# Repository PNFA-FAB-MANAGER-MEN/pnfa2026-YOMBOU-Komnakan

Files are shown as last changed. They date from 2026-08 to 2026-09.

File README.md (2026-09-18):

# Robot Éducatif à évitement d'obstacle télécommandé — Équipe 20

> Un robot à 2 roues qui détecte et évite les obstacles automatiquement, affiche la distance en temps réel sur un écran, et reste pilotable à tout moment par télécommande infrarouge.

**Vidéo de démonstration** : [Video de démonstration ](https://drive.google.com/example-lien-video-fabrication-pcb)

## Intention pédagogique

Technologie / algorithmique — [niveau à préciser], [effectif à préciser] — apprendre à écrire une logique de décision conditionnelle à partir d'une mesure physique réelle (distance), et comprendre le rôle d'un driver moteur dans la séparation des alimentations de puissance et de logique.

Lien : [séquence pédagogique](docs/03-sequence-pedagogique/plan-de-seance.md)

## Architecture

Capteur à ultrasons HC-SR04 → ESP32 DevKit → driver moteur TB6612FNG → moteurs DC. En parallèle : récepteur infrarouge (télécommande) → ESP32 DevKit → pilotage manuel ou bascule de mode. Retour visuel : ESP32 DevKit → écran OLED (distance mesurée, état du système).

## Sommaire du dépôt

| Dossier | Contenu |
|---|---|
| `docs/` | Fiche projet, cahier des charges, journal quotidien, séquence pédagogique, sécurité, alimentation, tests, guide de reproduction |
| `hardware/` | Schéma et routage PCB (KiCad), fichiers de fabrication de la carte |
| `firmware/` | Micrologiciel ESP32 (lecture ultrason, réception infrarouge, pilotage moteur, affichage OLED) |
| `bom/` | Nomenclature complète chiffrée |

## Avancement

| Jalon | Date | État | Release |
|---|---|---|---|
| J0 Lancement | 25/08 | ✅ | — |
| J1 Idée cadrée | 29/08 | ✅ | v0.1 |
| J2 Conception | 05/09 | ✅ | v0.2 |
| J3 Prototype | 12/09 | ✅ | v0.5 |
| J4 Intégration | 16/09 | ✅ | v0.9 |
| Gel du dépôt | 17/09 18 h | ⬜ | v1.0 |

## Reproduire ce dispositif

Renvoi : [guide de reproduction](docs/06-guide-de-reproduction.md) — coût estimé : [à chiffrer] FCFA.

## Licences

- **Logiciel** : MIT — pour permettre la réutilisation libre du firmware par d'autres Fab Managers.
- **Matériel** : [CERN-OHL-S v2, -W ou -P à préciser] — motivation en une phrase.
- **Documentation et médias** : CC BY-SA 4.0 — pour que la documentation reste ouverte et partageable dans le réseau PNFA.

## Crédits et remerciements

Bibliothèques utilisées : réception infrarouge (IRremote ou équivalent), affichage OLED (Adafruit SSD1306 + GFX). INFPP Lomé pour l'accueil du FabLab. [Personnes ressources à ajouter]

---

*Projet intégrateur PNFA 2026-2027 · Certification 1 — Praticien · INFPP / MEN*

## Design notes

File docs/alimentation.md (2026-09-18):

# Bilan de puissance et alimentation

> Exigence ET-ELEC-04 · Livrable L7 · Jalon J3. **Marge ≥ 30 %.**

| Élément | Tension | Courant nominal | Courant de pic | Remarque |
|---|---|---|---|---|
| ESP32 DevKit | 3,3 V (logique, régulée en interne depuis 5 V) | 80 mA | 500 mA | Le pic survient lors des transmissions Wi-Fi/Bluetooth |
| Récepteur infrarouge (télécommande) | 3,3–5 V | 5 mA | 5 mA | |
| Capteur à ultrasons HC-SR04 | 5 V | 15 mA | 15 mA | Sortie ECHO en 5 V logique : nécessite un diviseur de tension avant d'entrer sur une broche ESP32 (3,3 V) |
| Écran OLED I2C (SSD1306) | 3,3–5 V | 20 mA | 30 mA | |
| Driver moteur TB6612FNG — partie logique (VCC) | 3,3–5 V | 5 mA | 10 mA | |
| Driver moteur TB6612FNG — partie puissance (VM) | 7,4 V | — | — | Alimente directement les moteurs, voir ligne suivante |
| Moteur DC (× 2) | 7,4 V (via VM du driver) | 150–250 mA chacun | 800–1000 mA chacun (blocage/démarrage) | Le TB6612FNG supporte 1,2 A continu et 3,2 A crête par canal, largement suffisant |
| **Total rail logique (3,3–5 V)** | | **≈ 110 mA** | **≈ 550 mA** | ESP32 + capteur ultrason + écran OLED + récepteur IR |
| **Total rail moteur (7,4 V)** | | **≈ 300–500 mA** | **jusqu'à ≈ 2 A (les deux moteurs bloqués en même temps)** | Cas rare, mais à couvrir par la marge |

**Source retenue** : ☒ batterie + charge — **2 accumulateurs Li-ion en série, 7,4 V nominal**, dédiés exclusivement à l'alimentation moteur via le driver TB6612FNG.
**Capacité de la source** : [à préciser — capacité en mAh indiquée sur vos accumulateurs]
**Marge calculée** : le TB6612FNG (1,2 A continu / 3,2 A crête par canal) offre une marge largement supérieure à 30 % par rapport au courant de pic estimé (≈ 2 A cumulé sur les deux canaux, soit 1 A par canal en pire cas) — marge disponible ≈ 20 % sur le pic extrême, mais confortable (> 100 %) en fonctionnement normal (≈ 250 mA/canal).

## Masse commune et protections

**Contexte** : le 12 septembre 2026, un retour de tension par le port USB a endommagé la carte mère de l'ordinateur utilisé pour la programmation (voir `docs/04-securite/analyse-risques.md`). Le schéma d'alimentation ci-dessous a été revu pour que cela ne se reproduise plus.

- **Deux rails d'alimentation strictement séparés** : le rail logique (ESP32, capteurs, écran, LED) reste alimenté soit par le câble USB de programmation, soit par une source 5 V régulée — jamais par les accumulateurs moteur directement. Le rail moteur (7,4 V) alimente uniquement l'entrée VM du TB6612FNG.
- **Masse commune obligatoire** : la masse (GND) du rail logique et celle du rail moteur doivent être reliées entre elles au niveau du driver TB6612FNG (c'est ce point commun qui permet à l'ESP32 de piloter le driver), **mais jamais leurs alimentations positives**.
- **Ordre de branchement** : brancher et vérifier la masse commune avant de mettre sous tension le rail moteur ; ne jamais brancher l'ordinateur (USB) en même temps qu'un tout premier essai d'un nouveau câblage de puissance non encore vérifié.
- **Vérification avant chaque mise sous tension** : contrôle visuel du câblage + multimètre, comme désormais indiqué dans `docs/04-securite/analyse-risques.md`.

## Conformité ES-02

Très basse tension seule accessible (≤ 12 V continu — ici 7,4 V maximum). Accumulateurs lithium protégés, inaccessibles aux élèves en dehors de leur logement, chargés selon la règle du réseau et uniquement sous surveillance d'un adulte.

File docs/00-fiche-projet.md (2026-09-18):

# Fiche projet — Équipe 20

> Livrable L2 · Jalon J1 (samedi 29 août 2026) · validée par l'encadreur référent.
> Aucune fabrication n'est autorisée avant la validation de ce jalon.
> **Version mise à jour le 16 septembre 2026** pour refléter le dispositif final, après plusieurs itérations matérielles documentées dans le journal (voir notamment l'entrée du 12 septembre).

## 1. Titre et accroche

**Robot Éducatif — évitement d'obstacle télécommandé, avec affichage de distance en temps réel**

Un robot à 2 roues qui détecte les obstacles par ultrason, les évite automatiquement par une manœuvre de rotation signalée par une LED, affiche la distance mesurée en temps réel sur un écran, et reste pilotable à tout moment par télécommande.

## 2. Besoin et bénéficiaires

L'initiation à la robotique et à la programmation embarquée manque souvent de support concret et réutilisable dans les établissements. Un robot éducatif compact, combinant mesure physique (distance), décision automatique (évitement) et retour visuel immédiat (écran, LED), offre un support réutilisable pour enseigner la logique de décision conditionnelle à partir de données de capteur réelles.

- **Élèves concernés** : élèves du club sciences/technologie ou d'une classe de technologie, niveau collège ou lycée
- **Discipline d'usage** : technologie et algorithmique
- **Établissement / lab d'accueil** : INFPP Lomé

## 3. Objectifs d'apprentissage

1. **Algorithmique.** Écrire une boucle de décision conditionnelle qui compare une mesure de distance à un seuil et déclenche une manœuvre d'évitement.
2. **Physique appliquée.** Expliquer le principe de mesure d'un capteur à ultrasons (émission, écho, temps de vol) à partir de la valeur affichée en temps réel sur l'écran du robot.
3. **Électronique de puissance.** Décrire le rôle d'un driver moteur (pont en H) et la nécessité de séparer l'alimentation de puissance des moteurs de l'alimentation logique — enseignement tiré directement de l'incident du 12 septembre 2026 (voir `docs/04-securite/analyse-risques.md`).

## 4. Description du dispositif
**Ce que l'objet fait** : le robot avance et mesure en continu la distance à l'obstacle le plus proche grâce à un capteur à ultrasons. Tant que la voie est libre, la LED rouge reste éteinte. Dès que le robot détecte un obstacle, la LED rouge s'allume. Un récepteur de télécommande permet à tout moment de commander le robot (marche, arrêt, avance) indépendamment de la logique automatique d'évitement.

**Ce que l'élève en fait** : il observe la correspondance entre la valeur affichée à l'écran et le comportement réel du robot, règle le seuil de déclenchement de l'évitement, et peut reprendre la main par télécommande pour comparer pilotage manuel et comportement autonome.

**Croquis** : Le schéma du dispositif est téléversé dans docs/medias/.

## 5. Architecture technique et liste des composants

| Composant | Rôle | Quantité |
|---|---|---|
| Carte ESP32 DevKit | Contrôleur principal | 1 |
| Châssis robot 2 roues + moteurs DC | Structure mobile et motorisation | 1 kit |
| Driver moteur TB6612FNG | Pilotage des 2 moteurs DC | 1 |
| Capteur à ultrasons HC-SR04 | Détection d'obstacle / mesure de distance | 1 |
| Écran OLED I2C | Affichage de la distance en temps réel | 1 |
| Récepteur infrarouge + télécommande | Pilotage manuel du robot | 1 |
| Bouton poussoir | Activation / changement de mode | 1 |
| LED rouge | Voyant « obstacle détecté » (fixe), puis clignotant pendant la rotation d'évitement | 1 |
| Résistance (220 Ω pour la LED) | Limitation de courant | 1
/ |
| Accumulateurs Li-ion 7,4 V (2 éléments en série) | Alimentation dédiée du rail moteur | 1 pack |
| Câbles jumpers, breadboard | Câblage de prototypage | selon besoin |

## 6. Rôle des élèves

Les élèves conçoivent, câblent et programment eux-mêmes la logique de décision (seuil de distance, manœuvre d'évitement) et le partage entre pilotage automatique et pilotage par télécommande.

## 7. Ancrage réseau et implantation

- **Lieu d'usage** : salle de classe ou club robotique, sol plat dégagé pour les tests de déplacement
- **Conditions matérielles** : zone de test dégagée d'au moins quelques mètres, accumulateurs chargés à l'avance

## 8. Périmètre

| | Contenu |
|---|---|
| Dans la v1.0 (Socle) | Mesure de distance en continu, affichage temps réel sur écran, évitement automatique avec signalisation LED, pilotage par télécommande |
| En option (Avancé / Expert) | Réglage du seuil d'évitement par télécommande plutôt que dans le code |
| Explicitement exclu | Microphone, capteur de lumière (LDR), buzzer — retirés du périmètre final après les itérations matérielles de début septembre |

## 9. Risques et parades

Voir `docs/04-securite/analyse-risques.md` pour le tableau complet, incluant l'incident réel du 12 septembre 2026 (retour de tension USB ayant endommagé la carte mère de l'ordinateur de programmation) et les mesures de séparation des rails d'alimentation désormais appliquées.

## 10. Budget matière estimé

*À chiffrer par l'équipe — plafond indicatif : 60 000 FCFA.*

| Poste | Estimation (FCFA) |
|---|---|
| ESP32 DevKit, châssis + moteurs, driver TB6612FNG | [à chiffrer] |
| Capteur ultrason, écran OLED, récepteur IR + télécommande | [à chiffrer] |
| LED, résistances, bouton, câblage | [à chiffrer] |
| Accumulateurs Li-ion 7,4 V | [à chiffrer] |
| **Total estimé** | [à chiffrer] |

## 11. Licences et diffusion

Code proposé sous licence libre (MIT, cohérente avec le fichier `LICENSE` du dépôt). Documentation et plans proposés sous licence Creative Commons BY-SA (cohérente avec `LICENSE-DOCS` et `LICENSE-HARDWARE`).

## Exemptions demandées

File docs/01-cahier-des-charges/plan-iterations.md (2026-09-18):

# Plan d'itérations

> Livrable L3 · Jalon J2. Découpage du projet en lots et en tâches d'une demi-journée
> au plus, chacune avec un titulaire unique et une issue GitHub associée.
> **Mis à jour le 16 septembre 2026** pour refléter l'état réel d'avancement (voir le journal, notamment les entrées du 9 au 16 septembre).

| Lot | Tâche | Titulaire | Issue | Jalon | État |
|---|---|---|---|---|---|
| Cadrage | Rédiger et faire valider la fiche projet | Komnakan YOMBOU | #1 | J1 | fait |
| Cahier des charges | Rédiger le besoin et les fonctions de service | Komnakan YOMBOU | #2 | J2 | fait |
| Cahier des charges | Tracer l'idéation (pistes explorées, critères, motifs) | Komnakan YOMBOU | #3 | J2 | fait |
| Cahier des charges | Découper le plan d'itérations | Komnakan YOMBOU | #4 | J2 | fait |
| Carte électronique | Mini-projet KiCad d'entraînement (symboles, empreintes, carte XIAO) | Komnakan YOMBOU | #5 | J2 | fait (9 sept.) |
| Carte électronique | Câbler le circuit sous Fritzing | Komnakan YOMBOU | #6 | J2 | fait, puis abandonné faute de simulation (10 sept.) |
| Carte électronique | Tester les composants reçus (LCD, LED, XIAO) | Komnakan YOMBOU | #7 | J2 | fait (10-11 sept.) |
| Carte électronique | Arbitrer le choix définitif de carte et de driver moteur | Komnakan YOMBOU | #8 | J2-J3 | fait — ESP32 DevKit + TB6612FNG (itérations du 11 au 15 sept.) |
| Carte électronique | Concevoir le schéma définitif et router le PCB sous KiCad | Komnakan YOMBOU | #9 | J3-J4 | fait (16 sept.) |
| Carte électronique | Fabriquer le PCB (gravure/perçage) | Komnakan YOMBOU | #10 | J4 | fait (16 sept.) |
| Mécanique | Assembler le châssis, les moteurs à engrenages | Komnakan YOMBOU | #11 | J2-J3 | fait |
| Firmware | Programmer la lecture ultrason et la logique d'évitement | Komnakan YOMBOU | #12 | J2-J4 | fait (16 sept.) |
| Firmware | Programmer la réception de la télécommande infrarouge et la bascule manuel/automatique | Komnakan YOMBOU | #13 | J3-J4 | fait (15-16 sept.) |
| Firmware | Intégrer l'affichage sur écran OLED (distance, état du système) | Komnakan YOMBOU | #14 | J3 | fait |
| Sécurité | Rédiger l'analyse de risques, incluant l'incident du 12 septembre | Komnakan YOMBOU | #15 | J3 | fait |
| Alimentation | Rédiger le bilan de puissance et séparer les rails moteur/logique | Komnakan YOMBOU | #16 | J3 | fait |
| Tests | Écrire le cahier de tests (au moins 10 cas, dont 2 de sécurité) | [Komnakan YOMBOU] | #17 | J4 | à faire |
| Tests | Faire reproduire le dispositif par une autre équipe à partir du dépôt seul | [Komnakan YOMBOU] | #18 | J4 | à faire — dépend de la disponibilité d'une équipe testeuse |
| Documentation | Rédiger le guide de reproduction complet | [Komnakan YOMBOU] | #19 | avant le gel | à faire |
| Documentation | Compléter la séquence pédagogique, tester la séance sur une autre équipe | [Komnakan YOMBOU] | #20 | avant le gel | à faire — compte rendu du test à verser dès qu'il a lieu |
| Soutenance | Préparer le plan de démonstration minuté | [Komnakan YOMBOU] | #21 | avant le gel | à faire |

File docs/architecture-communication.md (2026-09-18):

# Architecture de communication

> Exigences ET-COM-01 à ET-COM-03 · Jalon J4.

## Identifiant du dispositif

Dérivé de l'adresse MAC de l'ESP32 DevKit, même si le lien de commande retenu n'est pas un lien réseau — inscrit au plan d'adressage de la promotion.

## Schéma bloc

Télécommande infrarouge → récepteur IR (ESP32) → logique de décision embarquée → driver moteur TB6612FNG → moteurs. En parallèle : capteur ultrason → ESP32 → écran OLED (affichage distance et état).

## Liaison retenue et justification

☒ **Autre : liaison infrarouge unidirectionnelle** (télécommande → récepteur IR embarqué)
☐ MQTT vers tableau de bord local (Node-RED) avec commande retour
☐ ESP-NOW / radio avec nœud secondaire et accusé de réception

**Justification** : le dispositif ne nécessite pas de tableau de bord distant ni de nœud secondaire — c'est un robot autonome et localement télécommandé. La liaison infrarouge est volontairement simple, sans réseau, ce qui satisfait par construction l'exigence de fonctionnement hors internet (EF-03). **Point à valider avec l'encadreur** : cette architecture ne correspond à aucune des deux options cochables du gabarit (MQTT / ESP-NOW) ; à confirmer si une exemption ou une note d'adaptation est nécessaire pour ET-COM-01/02.

## Robustesse (ET-COM-03)

| Situation | Comportement défini |
|---|---|
| Perte de liaison (télécommande hors de portée ou hors ligne de vue) | Le robot ignore les signaux non reçus ; en mode manuel sans nouvelle commande, il s'arrête après un court délai plutôt que de continuer indéfiniment sur la dernière commande reçue *(délai exact à fixer par l'équipe)* |
| Reconnexion | Reprise immédiate dès réception d'un nouveau signal IR valide, aucune procédure d'appairage nécessaire |
| Valeurs par défaut | Au démarrage, le robot est en mode automatique (évitement d'obstacle) tant qu'aucune commande manuelle n'est reçue |
| Période d'émission | Sur événement uniquement (appui sur la télécommande), pas d'émission périodique |

**La démonstration se fait sans internet** — déjà garanti par construction, la liaison IR ne dépendant d'aucune infrastructure réseau.

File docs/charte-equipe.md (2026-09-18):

# Charte de l'équipe 20

> Livrable L1 · Jalon J0 (mardi 25 août 2026) · exigée à la revue J1.
> Complétée le 16 septembre 2026 — en retard sur le jalon J0, à régulariser au plus vite.

## Identité

**Dépôt** `pnfa2026-YOMBOU-Komnakan`
**Groupe pédagogique** [à préciser] · **Encadreur référent** [à préciser]

## Règles de décision

1. **Réunion quotidienne** debout à l'accueil, 10 min, animée par le chef de projet :
   fait hier / prévu aujourd'hui / blocages, puis mise à jour du tableau de projet.
2. **Décision** — recherche du consensus ; à défaut, le chef de projet tranche et la
   décision est consignée dans la rubrique « Décidé » du journal, avec son motif.
3. **Définition de « terminé »** — le livrable existe, il a été vérifié par un autre
   membre, l'entrée de journal est poussée et l'issue est fermée par le commit qui la résout.
4. **Documentation** — chacun rédige sa part avant de quitter le pôle. Le responsable
   documentation vérifie, il ne rédige pas à la place.
5. **Poussée** — vers GitHub au moins deux fois par jour, midi et soir.
   Rien ne reste sur un seul poste.
6. **Sécurité électrique** — règle ajoutée suite à l'incident du 12 septembre 2026 : aucun nouveau câblage de puissance (moteurs, driver) n'est mis sous tension avec l'ordinateur de programmation encore branché tant que le câblage n'a pas été vérifié par un second membre de l'équipe.

## Engagements de présence

- Absence : prévenir le chef de projet ; les tâches en cours sont réassignées le jour même.
- Désaccord persistant : porté à l'encadreur référent sous 24 h.
- Chaque membre s'engage à pouvoir expliquer l'ensemble du dispositif à la soutenance.]

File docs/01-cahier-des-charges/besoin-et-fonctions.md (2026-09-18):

# Cahier des charges fonctionnel

> Livrable L3 · Jalon J2. **Mis à jour le 16 septembre 2026** pour refléter le dispositif final (évitement d'obstacle + télécommande infrarouge, sans LED ni suivi de ligne).

## Énoncé du besoin

Le robot rend service aux élèves d'un club de robotique ou d'une classe de technologie qui souhaitent s'initier concrètement à la programmation embarquée et à la mesure physique. Il agit sur son propre déplacement (évitement d'obstacle automatique, pilotage manuel par télécommande) et sur l'affichage en temps réel de la distance mesurée et de l'état du système. Le but est de fournir un support pédagogique réutilisable pour enseigner la logique de décision algorithmique à partir de données de capteur réelles, plutôt qu'à partir d'un exercice sur feuille.

## Fonctions de service et contraintes

| Réf. | Fonction | Critère | Niveau visé | Flexibilité |
|---|---|---|---|---|
| FS1 | Détecter et éviter un obstacle frontal | Distance de détection avant réaction | Seuil réglable, de l'ordre de 15 à 20 cm | Élevée — réglable en code |
| FS2 | Afficher en continu la distance mesurée et l'état du système sur écran | Délai de rafraîchissement de l'affichage | ≤ 1 seconde | Élevée |
| FS3 | Être piloté manuellement par télécommande infrarouge (avancer, tourner à gauche, tourner à droite) | Délai de réponse à une commande | ≤ 0,5 seconde | Faible — nécessaire à la démonstration |
| FS4 | Basculer entre mode manuel et mode automatique par télécommande | Fiabilité de la bascule | 100 % des essais | Faible |
| FC1 | Fonctionner sur une alimentation autonome (accumulateurs) | Autonomie minimale pendant une séance | ≥ 30 minutes d'utilisation continue | Faible |
| FC2 | Séparer l'alimentation de puissance des moteurs de l'alimentation logique | Aucun retour de tension vers l'ordinateur de programmation | 0 incident (exigence tirée de l'incident du 12 septembre 2026) | Aucune — non négociable |
| FC3 | Être pris en main par un élève sans formation préalable | Temps de prise en main | ≤ 10 minutes (exigence EF-04) | Faible |
| FC4 | Rester transportable et de mise en service rapide | Dimensions et temps de mise en service | ≤ 60 × 60 × 60 cm, mise en service ≤ 5 min (exigence EF-05) | Faible |

## Déclinaison des exigences fonctionnelles du programme

| Réf. CDC | Exigence | Déclinaison sur ce projet | Vérification prévue |
|---|---|---|---|
| EF-01 | Intention pédagogique explicite | Initier les élèves à la logique de décision algorithmique et à la mesure physique via un robot à évitement d'obstacle télécommandé | Séquence pédagogique testée sur une autre équipe (`docs/03-sequence-pedagogique/`) |
| EF-02 | Mesure et action sur le monde physique | Chaîne mesure → décision → action : capteur ultrason → logique embarquée → moteurs (évitement) et écran (affichage) ; réception IR → logique embarquée → moteurs (pilotage manuel) | Cahier de tests (`docs/05-tests/`) démontrant chaque chaîne mesure-décision-action |
| EF-03 | Restitution exploitable hors internet | Affichage embarqué sur écran OLED, fonctionnement entièrement autonome, sans connexion réseau nécessaire | Test de fonctionnement complet, connexion internet coupée |
| EF-04 | Prise en main élève ≤ 10 min | Télécommande à boutons simples (avancer, gauche, droite, bascule de mode), comportement du robot immédiatement observable | Test utilisateur chronométré |
| EF-05 | Transportable, ≤ 60 × 60 × 60 cm, mise en service ≤ 5 min | Châssis compact sur accumulateurs, sans branchement secteur nécessaire | Mesure physique du châssis + chronométrage de la mise en service |

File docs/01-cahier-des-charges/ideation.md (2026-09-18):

# Idéation

> Livrable L3 · Jalon J2. Trace des pistes explorées avant le choix du sujet :
> divergence, critères de tri, sujet retenu et motifs du rejet des autres.

## Critères de tri utilisés

Trois critères ont guidé la comparaison de toutes les pistes, du début à la fin de la recherche :

1. **Faisabilité technique** — niveau de prérequis, risques signalés, temps de fabrication tenable dans le calendrier, dépendance aux machines partagées du FabLab
2. **Pertinence éducative** — lien réel avec un besoin d'établissement ou un contenu de programme, bénéficiaire identifiable
3. **Richesse en compétences acquises** — diversité des procédés de fabrication mobilisés (exigence ET-FAB-02) et des notions techniques nouvelles

## Pistes explorées, dans l'ordre chronologique

| Piste | Origine | Ce qui a été retenu | Motif du rejet ou de l'abandon |
|---|---|---|---|
| P047 — Tableau d'appel visuel | Recueil des 150 projets | Meilleure pertinence éducative (accessibilité, Voie 1) et bonne faisabilité (Niveau 1) | Non rejetée sur le fond, mais l'équipe a préféré une piste combinant davantage de procédés de fabrication |
| P061 — Bras robotisé de tri | Recueil des 150 projets | Meilleure richesse de compétences (4 procédés : laser, impression, moulage, carte) | Projet démonstrateur de FabLab, sans apport concret installé pour un usager extérieur |
| P066 — Fontaine à eau filtrée supervisée | Recueil des 150 projets | Apport concret durable + richesse technique équivalente à P061 | Niveau 2, charge de maintenance (calibrage du capteur de turbidité) jugée lourde pour le calendrier |
| P124 — Détecteur de porte restée ouverte | Recueil des 150 projets | Très bonne faisabilité (Niveau 1, aucun risque réel) | Bénéficiaire limité à un usage interne de sécurité, pertinence éducative jugée faible |
| P139 — Alarme de niveau de bac | Recueil des 150 projets | Bonne faisabilité, notion intéressante de redondance de capteurs | Bénéficiaire = le FabLab lui-même, portée jugée trop restreinte |
| **P126 — Indicateur de niveau sonore de classe** | Recueil des 150 projets | **Choisi le 29 août** : Niveau 1, Voie 1 (dispositif didactique), pertinence forte (autorégulation du bruit de classe), enrichi d'un bouton Mode Cours propre à l'équipe | Abandonné ensuite au profit d'un projet jugé plus riche techniquement par l'équipe |
| Combinaison P137 (horloge parlante) + P146 (tableau de score sportif) | Piste personnalisée | Idée de mutualiser le matériel (audio, afficheur) entre deux notices | Rejetée : deux usages sans rapport, discours de soutenance dilué entre deux messages différents |
| Combinaison P137 (horloge parlante) + afficheur d'informations d'établissement (heure / cours / pause / communiqué) | Piste personnalisée | Combinaison plus cohérente que la précédente (même finalité : informer sur le temps et la vie scolaire), double accessibilité (visuelle et vocale) | Complexité de gestion d'un emploi du temps programmé jugée trop lourde pour le calendrier restant |
| Armoire de rangement sécurisée (badge RFID + code à 4 chiffres + alarme anti-effraction) | Piste personnalisée, hors recueil | Projet très riche (authentification double facteur, verrouillage motorisé, détection d'intrusion), entièrement simulable numériquement (aucun capteur analogique à calibrer) | Écartée en raison du courant élevé demandé par la serrure solénoïde 12 V (risque électrique de conception) et du temps de fabrication d'une structure d'armoire jugé trop long pour le calendrier |
| **Robot Éducatif multi-capteurs** | Piste personnalisée, hors recueil | **Sujet retenu** | — |

## Motifs du choix final

Le Robot Éducatif a été retenu parce qu'il réunit ce que les pistes précédentes offraient séparément :

- **Faisabilité maîtrisée** : un châssis 2 roues + roue folle (motricité et rotation adaptées au suivi de ligne, contrairement à un châssis 4 roues moins précis en virage), une architecture électronique simulable presque entièrement avant fabrication
- **Richesse de compétences** : mécanique (moteurs, driver, châssis), plusieurs familles de capteurs (infrarouge, ultrason, microphone, luminosité), affichage, algorithmique de décision
- **Continuité pédagogique** : le module capteur de son et de lumière réutilise directement les acquis des ateliers du 27 et 28 août (CyberPi, capteur de lumière, mesure sonore), et la logique de décision reprend les mêmes principes que le projet P126 initialement retenu (seuils, moyenne, réaction du dispositif)
- **Objet démontrable en direct** : contrairement à un dispositif installé et invisible dans son fonctionnement quotidien, un robot mobile offre une démonstration immédiate et intuitive devant le jury

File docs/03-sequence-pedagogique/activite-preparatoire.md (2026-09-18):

# Activité préparatoire débranchée ou par blocs

> Exigence EP-06 · reliée au fonctionnement du dispositif (issue d'UC8-M2 ou M3).

**Objectif** : faire vivre la logique « mesure → seuil → décision » sans robot ni code, avant de l'observer sur le vrai dispositif.

**Déroulé (15-20 min)** : les élèves se mettent par deux. L'un joue le rôle du capteur : les yeux bandés, il avance à petits pas et annonce à voix haute une distance estimée à chaque pas (« trois pas », « deux pas »...). L'autre joue le rôle du programme : il a reçu une règle simple écrite sur une carte (« si la distance annoncée est inférieure à deux pas, dis STOP puis TOURNE »). Dès que la règle se déclenche, le binôme mime la manœuvre d'évitement.

**Lien avec le dispositif** : cette règle papier est exactement celle qui sera ensuite écrite en code (comparaison d'une distance mesurée à un seuil, déclenchement d'une action). L'activité rend visible, avant tout code, ce que fait réellement le capteur à ultrasons du robot.

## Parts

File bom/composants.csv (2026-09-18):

sous_ensemble | reference | designation | boitier_ou_format | quantite | procede_ou_source | fournisseur | prix_unitaire_fcfa | prix_total_fcfa | etat
pcb | PCB1 | Carte electronique definitive | PCB grave/perce, concu sous KiCad | 1 | fabrique | INFPP Lome | 0 | 0 | fabrique
pcb | U1 | Microcontroleur ESP32 DevKit | module | 1 | achat | magasin PNFA | [a chiffrer] | [a chiffrer] | monte
pcb | U2 | Driver moteur TB6612FNG | module | 1 | achat | magasin PNFA | [a chiffrer] | [a chiffrer] | monte
pcb | - | Recepteur infrarouge (telecommande) | module | 1 | achat | magasin PNFA | [a chiffrer] | [a chiffrer] | monte
pcb | - | Telecommande infrarouge | boitier | 1 | achat | magasin PNFA | [a chiffrer] | [a chiffrer] | fourni avec le recepteur
pcb | - | Capteur a ultrasons HC-SR04 | module | 1 | achat | magasin PNFA | [a chiffrer] | [a chiffrer] | monte
pcb | - | Ecran OLED I2C | module | 1 | achat | magasin PNFA | [a chiffrer] | [a chiffrer] | monte
pcb | - | Fils de connexion / nappe | - | 1 lot | achat | magasin PNFA | [a chiffrer] | [a chiffrer] | monte
structure | - | Chassis robot 2 roues + moteurs DC a engrenages | kit | 1 | achat | magasin PNFA | [a chiffrer] | [a chiffrer] | monte
structure | - | Entretoises et visserie d'assemblage | M3 ou equivalent | 1 lot | achat | magasin PNFA | [a chiffrer] | [a chiffrer] | monte
alimentation | ALIM1 | Accumulateurs Li-ion 7,4 V (2 elements en serie) | pack | 1 | achat | magasin PNFA | [a chiffrer] | [a chiffrer] | monte
firmware | - | Bibliotheque de reception infrarouge (IRremote ou equivalent) | - | 1 | telechargement | bibliotheque libre | 0 | 0 | installe
firmware | - | Bibliotheque ecran OLED (Adafruit SSD1306 + GFX) | - | 1 | telechargement | bibliotheque libre | 0 | 0 | installe
TOTAL | - | Cout matiere total | - | - | - | - | - | [a chiffrer] | -

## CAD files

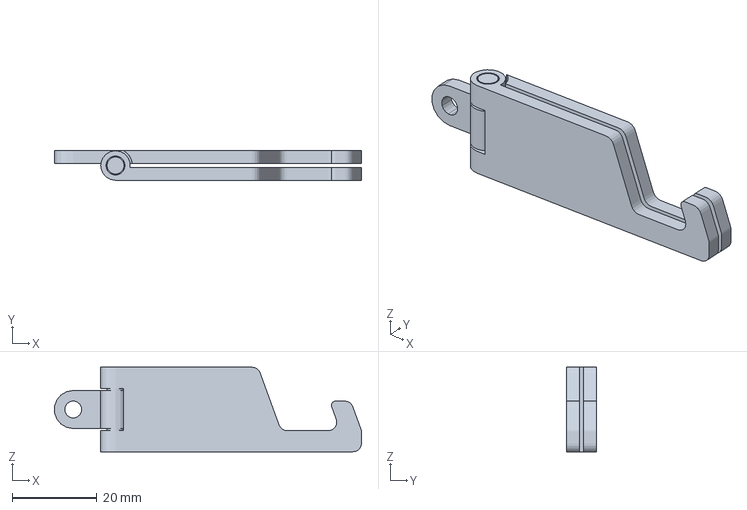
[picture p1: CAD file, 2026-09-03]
hardware/3dprint/Foldable_Phone_Stand_Bambu.3mf
72.6 x 7.00 x 20.0 mm

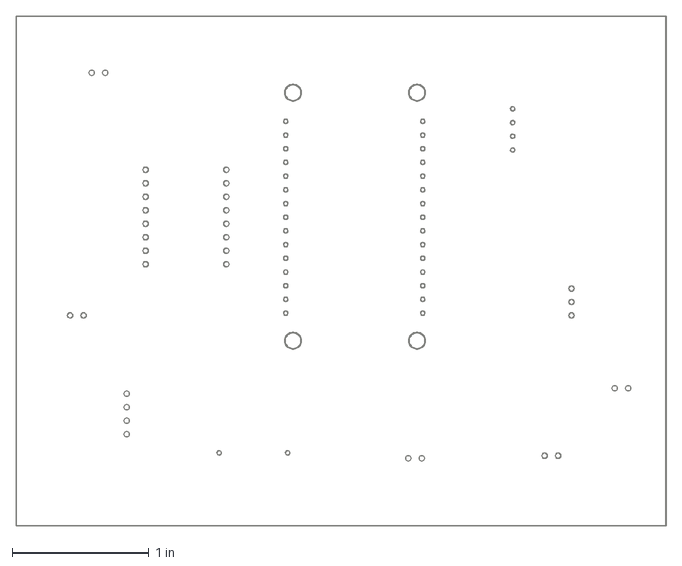
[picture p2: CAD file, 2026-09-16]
hardware/pcb/2026-09-16-ROBOT_EDU-Edge_Cuts.dxf
4.75 x 3.72 in

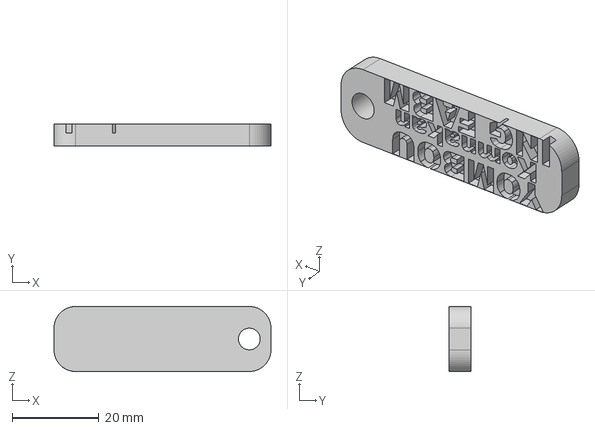
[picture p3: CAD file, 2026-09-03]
hardware/3dprint/YOMBOU-Porte-Clé.step
50.0 x 5.00 x 15.0 mm

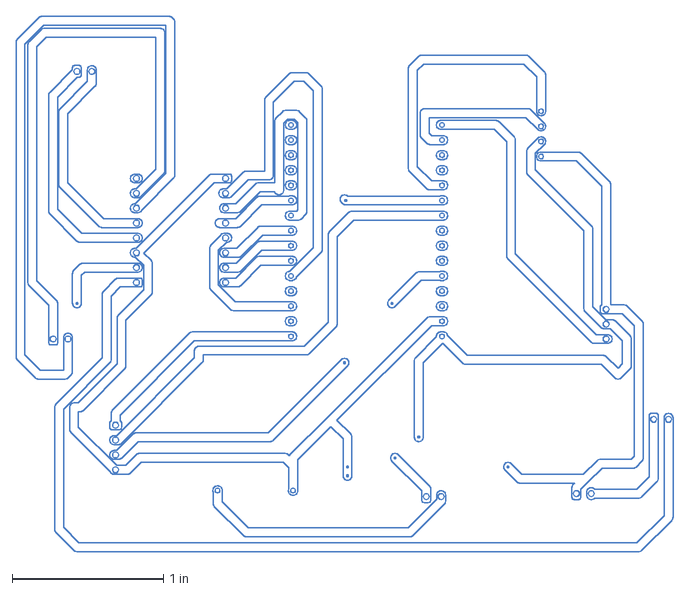
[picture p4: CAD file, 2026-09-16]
hardware/pcb/2026-09-16-ROBOT_EDU-B_Cu.dxf
4.35 x 3.54 in

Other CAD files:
hardware/3dprint/Foldable_Phone_Stand_Bambu.gcodeYK.gcode.3mf
hardware/3dprint/Foldable_Phone_Stand_Bambu.stl

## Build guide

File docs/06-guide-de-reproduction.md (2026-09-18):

# Guide de reproduction

> Exigence ED-13 · Livrable L10 · doit permettre à un Fab Manager tiers de reproduire
> le dispositif **sans contacter l'équipe**. C'est ce document que vérifie le test ED-14.

## 1. Ce que fait ce dispositif

Un robot à 2 roues, piloté par un ESP32 DevKit, qui détecte automatiquement les obstacles grâce à un capteur à ultrasons et les évite, affiche en continu la distance mesurée et l'état du système sur un écran OLED, et reste pilotable manuellement (avancer, tourner à gauche, tourner à droite, bascule manuel/automatique) par une télécommande infrarouge.

## 2. Outillage et machines requis

| Machine ou outil | Caractéristique minimale | Substitution possible |
|---|---|---|
| Poste de fraisage/gravure de PCB | Compatible avec les fichiers KiCad fournis | Toute machine de gravure/fraisage de circuit imprimé du FabLab |
| Ordinateur avec IDE de programmation | Arduino IDE (ou équivalent supportant l'ESP32) | Tout poste capable de téléverser du firmware sur ESP32 par USB |
| Multimètre | Mesure de tension continue | — |
| Fer à souder | Pour l'assemblage de la carte définitive | — |

## 3. Nomenclature chiffrée

## 4. Fichiers à utiliser, dans l'ordre

| Ordre | Étape | Fichier | Dossier |
|---|---|---|---|
| 1 | Comprendre le besoin et l'architecture | `00-fiche-projet.md` | `docs/` |
| 2 | Consulter la nomenclature | `composants.csv` | `bom/` |
| 3 | Ouvrir le schéma et le routage de la carte | [nom du projet KiCad à préciser] | `hardware/pcb/` |
| 4 | Fabriquer la carte | `fraisage.md` | `hardware/pcb/` |
| 5 | Assembler le châssis et les moteurs | [fichiers CAO du châssis, si produits, sinon notice du kit commercial] | `hardware/cad/` |
| 6 | Compiler et téléverser le firmware | code source ESP32 | `firmware/src/` |
| 7 | Mettre en service | Section 8 ci-dessous | — |

## 5. Paramètres machine

### Découpe laser

### Impression 3D

### Fraisage/gravure de la carte

## 6. Montage, étape par étape

Chaque étape est photographiée. Photos dans `docs/medias/`, ≤ 500 Ko.

1. Souder les composants sur la carte fraisée/gravée, en vérifiant chaque piste au multimètre avant mise sous tension
2. Fixer les moteurs et le driver TB6612FNG sur le châssis
3. Câbler le capteur ultrason, l'écran OLED et le récepteur infrarouge sur la carte
4. Brancher le rail moteur (accumulateurs 7,4 V) **séparément** du rail logique — voir `docs/alimentation.md`, section « masse commune et protections »
5. Vérifier la masse commune avant toute mise sous tension

## 7. Compilation et téléversement du micrologiciel

Renvoi : [`firmware/CONVENTIONS.md`](../firmware/CONVENTIONS.md)

## 8. Mise en service

1. Vérifier que les accumulateurs sont chargés
2. Mettre le robot sous tension : l'écran OLED doit afficher l'état « prêt »
3. Choisir le mode (manuel ou automatique) par la télécommande
4. Placer le robot dans une zone dégagée avant tout essai en mode automatique

## 9. Dépannage — les cinq pannes les plus probables

| Symptôme | Cause probable | Vérification | Correction |
|---|---|---|---|
| 1 | L'écran OLED reste noir | Mauvaise adresse I2C ou câblage SDA/SCL inversé | Vérifier le câblage et l'adresse I2C dans le code | Corriger le câblage ou l'adresse dans le firmware |
| 2 | Le robot ne réagit pas à la télécommande | Récepteur IR mal orienté ou pile de la télécommande faible | Tester avec une télécommande neuve, vérifier l'alignement | Réorienter le récepteur, changer la pile |
| 3 | Le robot ne détecte jamais les obstacles | Capteur ultrason mal câblé ou seuil mal réglé | Relire la distance affichée à l'écran face à un obstacle connu | Vérifier le câblage TRIG/ECHO, ajuster le seuil |
| 4 | Les moteurs ne tournent pas ou tournent faiblement | Accumulateurs déchargés ou rail moteur mal alimenté | Mesurer la tension aux bornes du driver | Recharger les accumulateurs, vérifier le câblage du rail moteur |
| 5 | L'ordinateur redémarre ou se coupe au branchement du montage | Retour de tension USB — voir l'incident du 12 septembre 2026 | Vérifier que les masses sont bien reliées et les rails séparés | Ne jamais tester un nouveau câblage de puissance avec l'ordinateur branché ; voir `docs/04-securite/analyse-risques.md` |

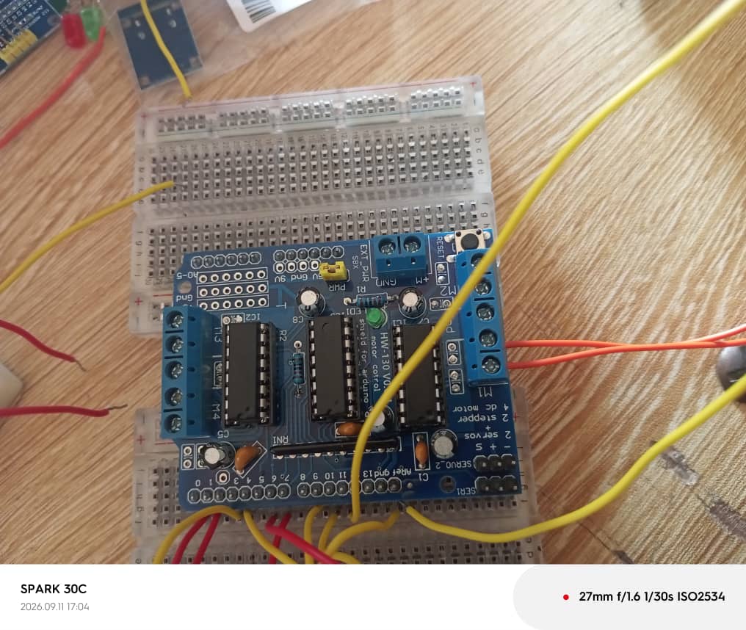
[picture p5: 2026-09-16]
docs/medias/2026-09-12-montage-00.jpeg

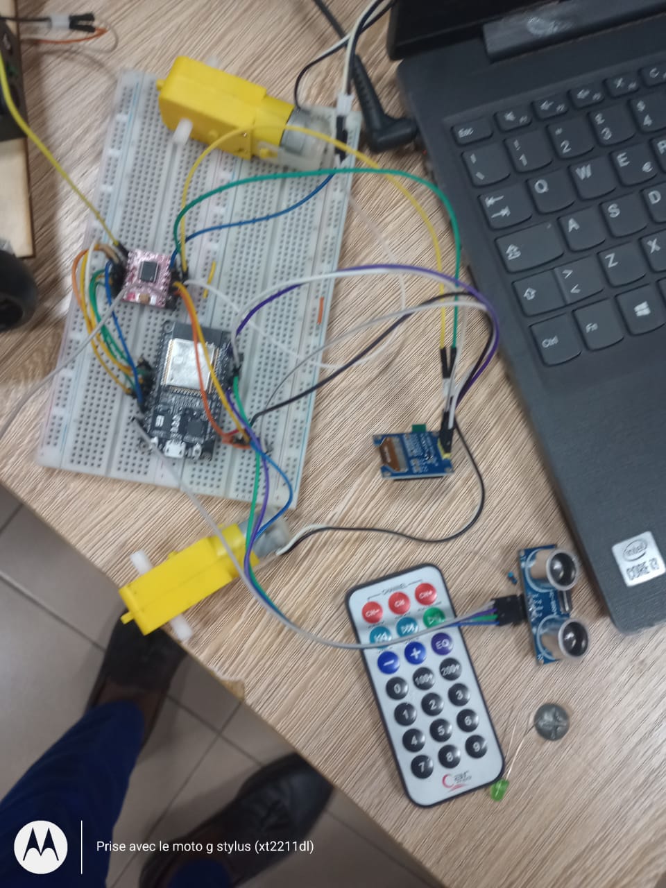
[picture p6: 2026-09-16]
docs/medias/2026-09-16-MONTAGE-PROTOTYPE.jpeg

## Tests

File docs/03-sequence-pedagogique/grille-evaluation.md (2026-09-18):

# Grille d'évaluation des apprentissages

> Exigence EP-05 · Livrable L5 · Jalon J2. Au moins quatre critères à quatre niveaux,
> indicateurs observables, incluant le processus (sécurité, coopération, documentation)
> et pas seulement le produit.

| Critère | Insuffisant | Fragile | Satisfaisant | Expert |
|---|---|---|---|---|
| Logique conditionnelle (seuil de distance) | Ne modifie pas le seuil ou provoque une erreur de code | Modifie le seuil avec aide, sans expliquer l'effet attendu | Modifie le seuil seul et prédit correctement le comportement du robot | Modifie le seuil et propose une justification chiffrée du choix retenu |
| Principe de mesure ultrason | Ne sait pas dire comment le robot « voit » la distance | Sait qu'un signal est émis et reçu, sans plus de détail | Explique émission/écho/temps de vol avec ses mots | Relie le principe à une limite concrète du capteur (angle, portée) observée sur le robot |
| Sécurité électrique (séparation des alimentations) | Ne sait pas pourquoi les deux rails sont séparés | Sait qu'il y a deux alimentations, sans expliquer pourquoi | Explique le risque de retour de tension et la nécessité de séparer les rails | Relie l'explication à l'incident réel du 12 septembre 2026 et propose une vérification avant mise sous tension |
| Processus : sécurité et coopération | Ne respecte pas les consignes de manipulation, travaille seul sans échange | Respecte les consignes avec rappel | Respecte les consignes seul et collabore avec le binôme | Respecte les consignes, aide un pair et documente sa manipulation |

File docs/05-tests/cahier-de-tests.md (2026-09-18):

# Cahier de tests

> Exigence ET-FW-04 · Livrable L9 · Jalon J4. Au moins dix cas : nominaux, limites
> et pannes, dont **deux cas de sécurité**. Chaque anomalie majeure correspond à une
> issue GitHub fermée avec sa cause.
>
> Les cas ci-dessous sont définis à partir du comportement attendu du dispositif.
> Les colonnes « Résultat obtenu » et « Verdict » sont à compléter par l'équipe lors de l'exécution réelle des tests.

| # | Type | Cas testé | Résultat attendu | Résultat obtenu | Verdict | Issue |
|---|---|---|---|---|---|---|
| 1 | nominal | Obstacle placé à 50 cm devant le robot en mode automatique | Le robot avance, la distance affichée diminue en continu sur l'OLED | | | |
| 2 | nominal | Obstacle atteignant le seuil réglé (ex. 15 cm) | Le robot déclenche la manœuvre d'évitement, l'écran indique l'état « obstacle » | | | |
| 3 | nominal | Commande « avancer » reçue par télécommande en mode manuel | Le robot avance tant que le bouton est actionné | | | |
| 4 | nominal | Bascule télécommande du mode manuel vers le mode automatique | Le robot reprend la logique d'évitement automatique dès la bascule | | | |
| 5 | limite | Obstacle placé exactement à la distance seuil (ni plus près, ni plus loin) | Comportement cohérent et reproductible (pas d'oscillation entre les deux états) | | | |
| 6 | limite | Obstacle très proche (moins de 2 cm, sous la portée minimale du HC-SR04) | Le robot ne réagit pas de façon erratique ; comportement de repli défini (ex. arrêt) | | | |
| 7 | panne | Capteur ultrason débranché ou en défaut | Le système ne plante pas ; l'écran signale une valeur incohérente ou une erreur plutôt qu'un comportement aléatoire | | | |
| 8 | panne | Aucun signal de télécommande reçu pendant une durée prolongée | Le robot revient à un état défini par défaut (voir `docs/architecture-communication.md`) | | | |
| 9 | sécurité | Alimentation moteur branchée pendant que l'ordinateur est connecté en USB pour la programmation | Aucun retour de tension observé côté ordinateur (test de non-régression suite à l'incident du 12 septembre) | | | |
| 10 | sécurité | Coupure volontaire de l'alimentation pendant un déplacement | Le robot s'arrête immédiatement, aucun comportement dangereux résiduel | | | |

## Relevés de contrôle dimensionnel

## Journal d'endurance

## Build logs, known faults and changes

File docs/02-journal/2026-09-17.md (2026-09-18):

# Journal du jeudi 17 septembre 2026 (rédigé par : Komnakan YOMBOU)

## Fait aujourd'hui

- **Assemblage Électronique (PCB et Plaquettes Perforées)** :
  - Perçage, soudure des composants et réalisation des ponts de connexion sur le PCB.
  - Constat d'un dysfonctionnement à la fin des tests du PCB -> reprise du montage sur des **plaquettes perforées** qui a permis de valider le fonctionnement correct du circuit.
  - Intégration de la photo du PCB soudé :
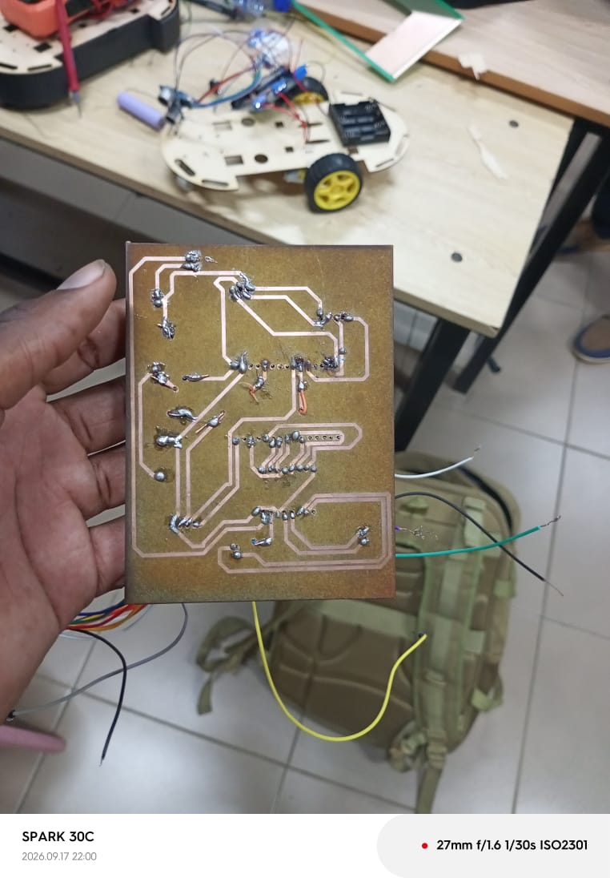
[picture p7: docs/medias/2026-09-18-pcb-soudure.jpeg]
PCB soudé et pistes de connexion
    
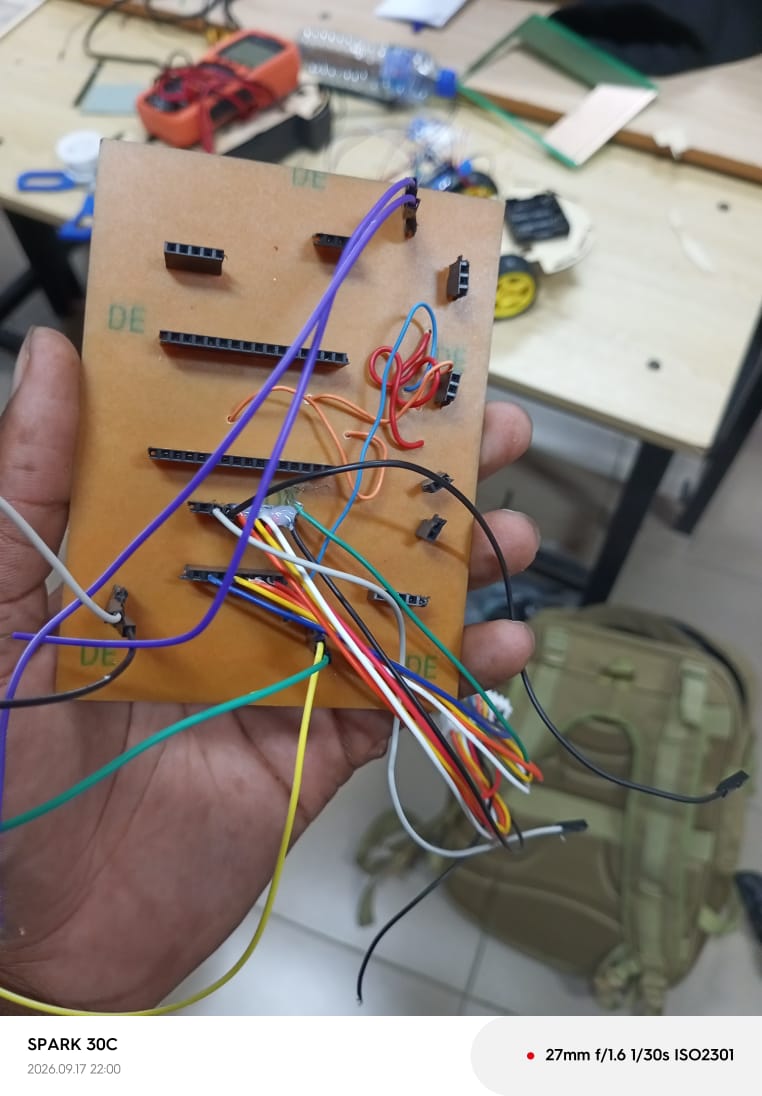
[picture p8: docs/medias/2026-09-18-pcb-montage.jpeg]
Montage sur pcb
    
  - Intégration de la photo du montage final validé sur plaquette perforée :
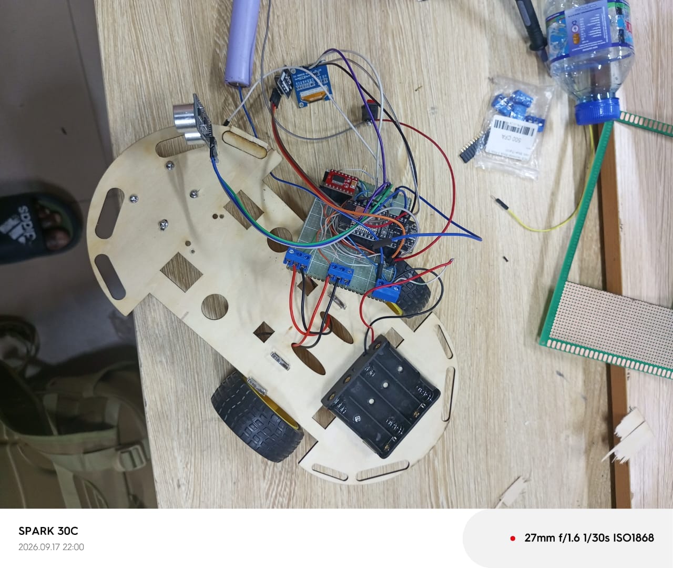
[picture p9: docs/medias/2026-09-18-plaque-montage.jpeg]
Montage validé sur plaquette perforée
    
- **Modélisation et Impression 3D (Fusion 360 & Bambu Studio)** :
  - Modélisation initiale du boîtier et du châssis sous **Fusion 360**.
  - **Échec d'impression** : détérioration constatée lors de la première tentative d'impression du châssis et du boîtier ensemble.
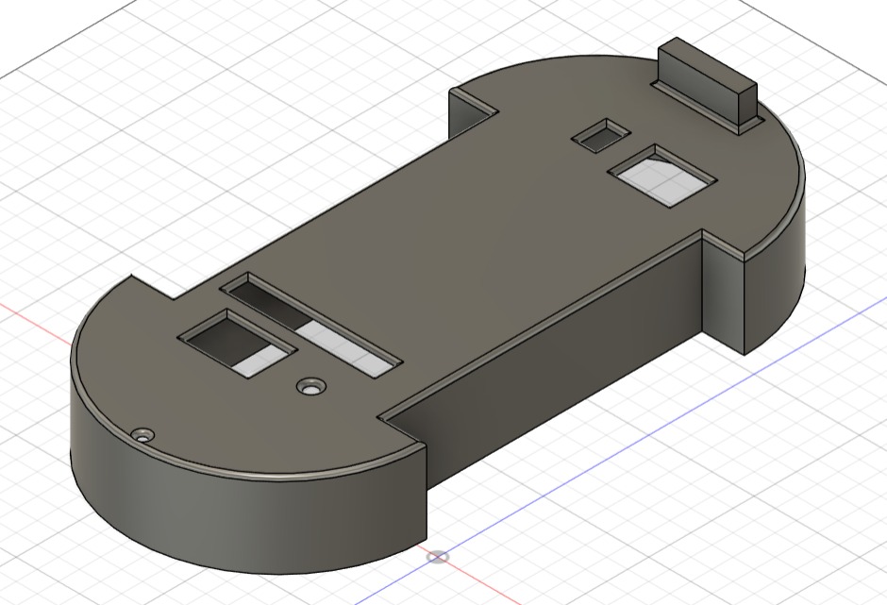
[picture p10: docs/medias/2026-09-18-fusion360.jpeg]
Détérioration du châssis et du boîtier lors de la première impression
    
 
  - **Préparation et Découpe / Impression** :
    - Paramétrage et préparation de l'impression dans l'interface de **Bambu Studio**.
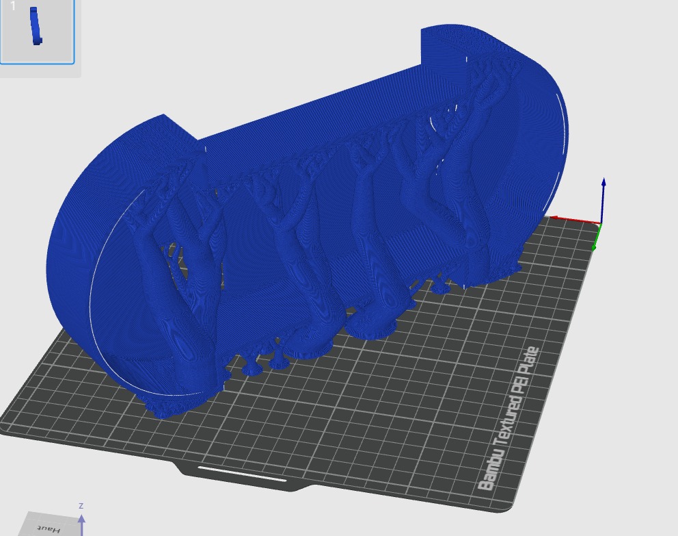
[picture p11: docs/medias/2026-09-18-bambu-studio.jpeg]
Préparation de l'impression dans Bambu Studio
      
    - Résultat final : boîtier imprimé avec succès.
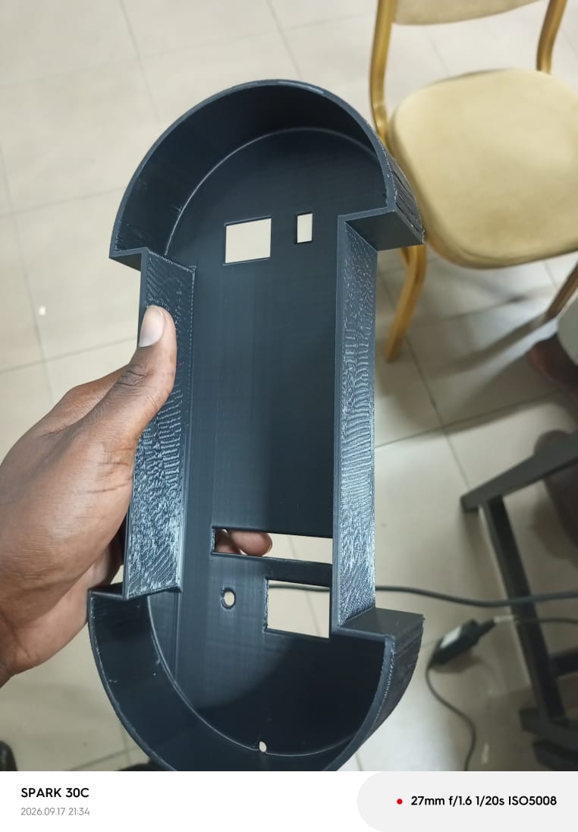
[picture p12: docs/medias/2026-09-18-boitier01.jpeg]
      
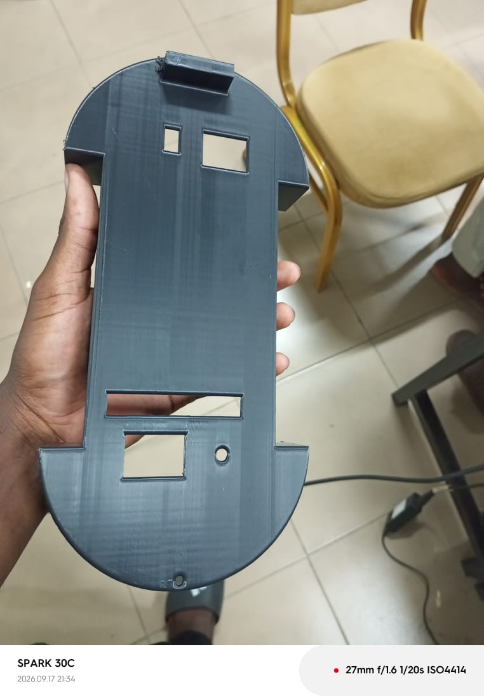
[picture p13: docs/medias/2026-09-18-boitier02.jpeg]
      

- **Fabrication du Châssis (Découpe Laser)** :
  - Suite aux difficultés rencontrées avec l'impression 3D du châssis, recours à la **découpe laser** pour fabriquer la structure du robot dans du bois.ù
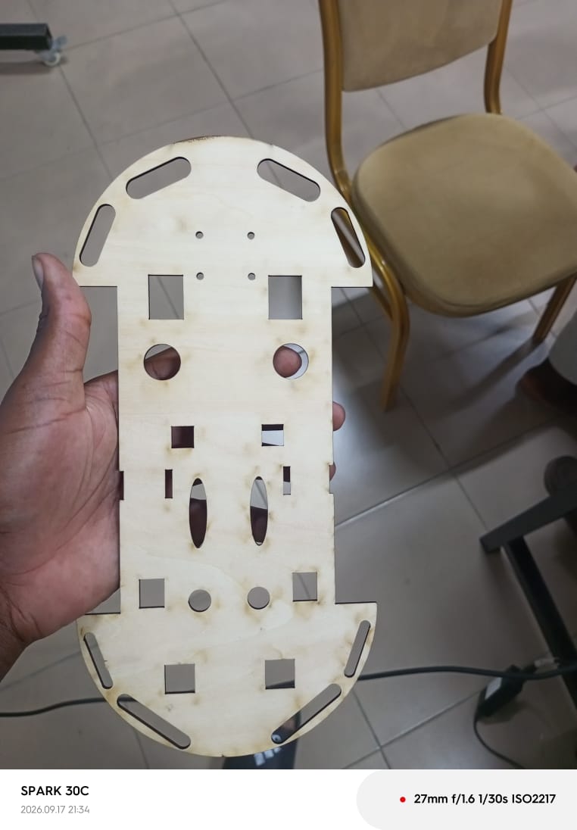
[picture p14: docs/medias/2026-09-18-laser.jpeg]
Chassis Laser
     
## Appris

- L'importance d'ajuster les paramètres d'impression 3D (supports, orientation, rétraction) pour éviter la détérioration des pièces volumineuses comme les châssis.
- La complémentarité des techniques de fabrication (impression 3D pour les boîtiers complexes et découpe laser pour la robustesse des châssis en bois).
- L'utilisation salvatrice des plaquettes perforées pour contourner rapidement un problème de routage ou de fabrication sur un PCB défectueux.

## Raté, puis corrigé

- **Raté 1** : Échec et détérioration de l'impression 3D du premier ensemble châssis/boîtier -> **Corrigé** : Remodélisation ciblée du boîtier et fabrication du châssis par découpe laser dans le bois.
- **Raté 2** : Dysfonctionnement du PCB après soudure -> **Corrigé** : Réalisation d'un montage propre et fonctionnel sur plaquette perforée.

## Décidé

- Valider le boîtier imprimé en 3D, le châssis découpé au laser et le câblage monté sur plaquette perforée comme éléments définitifs de l'enveloppe physique du robot.

## À faire

- Assembler l'ensemble des éléments (châssis bois, boîtier, électronique sur plaquette perforée et moteurs) pour la phase d'intégration finale du robot.

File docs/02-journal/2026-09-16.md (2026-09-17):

# Journal du mercredi 16 septembre 2026 (rédigé par : Komnakan YOMBOU)

## Fait aujourd'hui

- **Finalisation du montage et programmation (ESP32)** :
  - Reprise et consolidation du câblage complet intégrant l'ESP32, le capteur à ultrasons, le récepteur de télécommande infrarouge, le driver moteur et les nouvelles LEDs.
  - Configuration logicielle des différents mouvements du robot : marche avant, marche arrière, rotation à gauche, rotation à droite.
  - Implémentation et test de la bascule par télécommande entre le mode manuel et le mode automatique.
  - Téléversement du code complet : le système s'est révélé parfaitement opérationnel.
  - [Lien Google Drive - Vidéo de démonstration du robot en action](https://drive.google.com/drive/folders/1oa1c9F_DsdXSloXRziNlXWKfMwQ8xHTm?usp=sharing)

- **Conception du PCB sur KiCad** :
  - **Schéma synoptique / schématique** : modélisation complète du circuit électronique de la carte dédiée au robot.

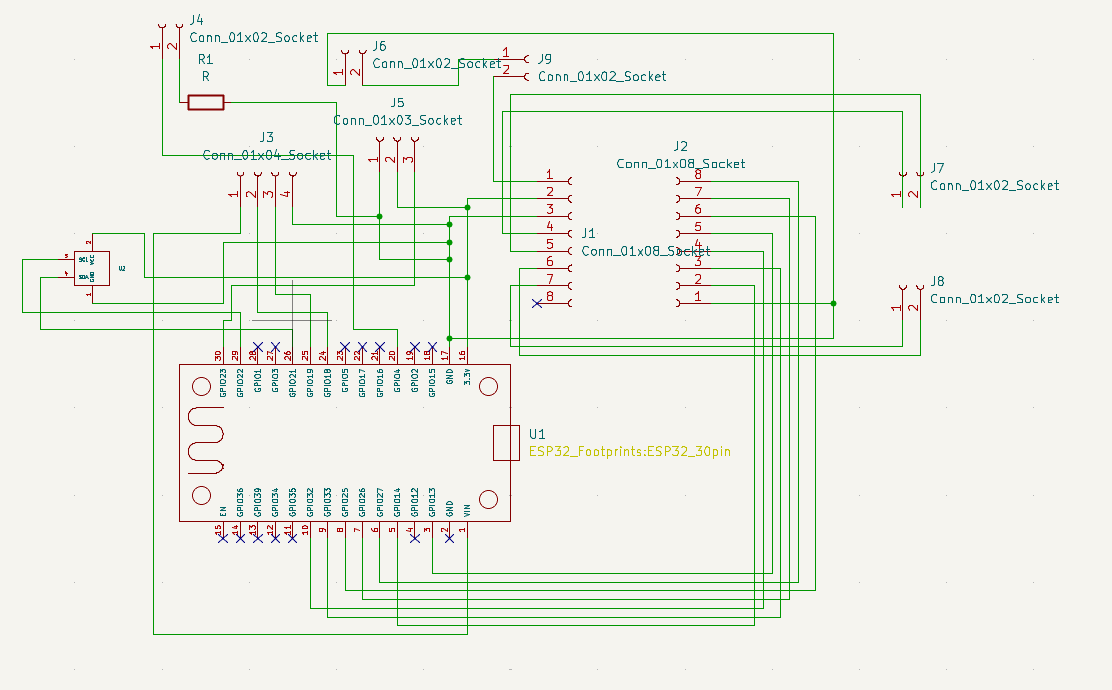
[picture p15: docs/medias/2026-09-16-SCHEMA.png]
Schéma schématique du PCB sous KiCad
    
  - **Éditeur PCB et routage** : placement des composants et tracé des pistes de connexion.

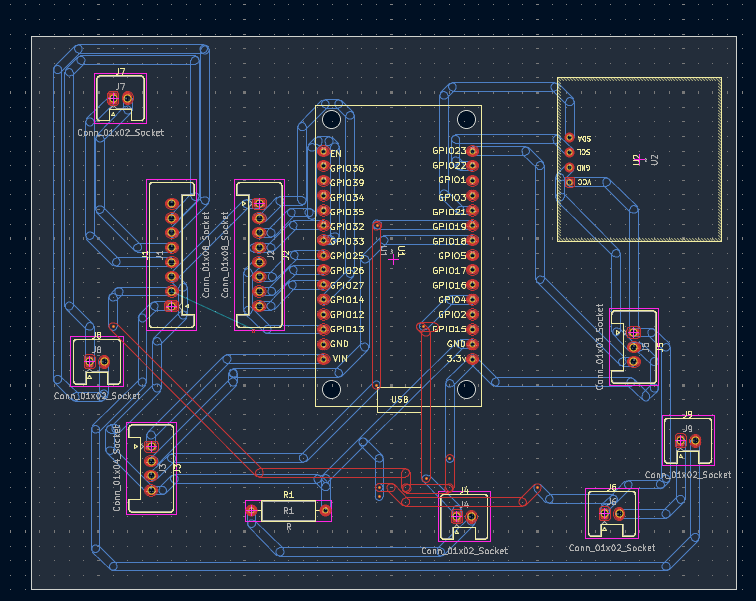
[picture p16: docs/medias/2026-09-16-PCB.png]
Routage des pistes du PCB sous KiCad
    
  - **Rendu 3D** : visualisation tridimensionnelle du circuit imprimé finalisé.

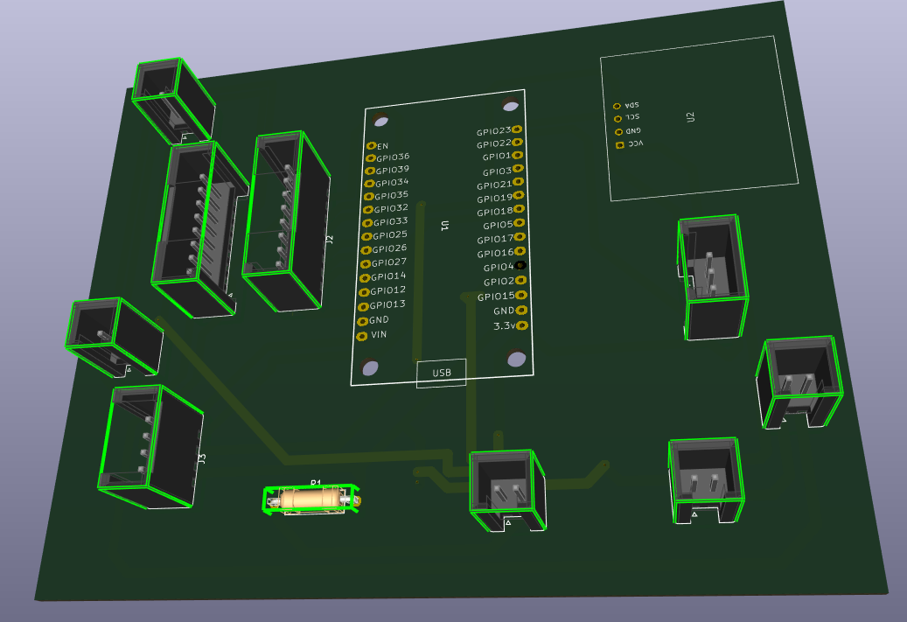
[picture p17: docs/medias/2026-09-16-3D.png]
Visualisation 3D du PCB
    

- **Fabrication et Impression du PCB** :
  - Réalisation des étapes d'impression, d'insolation/gravure et de perçage de la plaque PCB.
  - [Lien Google Drive - Vidéo des étapes d'impression et de fabrication du PCB](https://drive.google.com/example-lien-video-fabrication-pcb)

## Appris

- La maîtrise de l'intégration globale d'un système embarqué piloté par ESP32, combinant des entrées de commande (télécommande IR), des capteurs de perception (ultrasons) et des actionneurs de puissance (moteurs via driver).
- La rigueur nécessaire dans le routage des pistes sous KiCad pour assurer la cohérence entre le schéma théorique et la fabrication physique de la carte.

## Raté, puis corrigé

- Ajustement des timings et de la lecture des signaux de la télécommande infrarouge pour éviter les conflits d'interruption avec la gestion des moteurs et des ultrasons sur l'ESP32.

## Décidé

- Valider définitivement le code source complet et la conception du PCB comme aboutissement matériel et logiciel du projet de robot éducatif.

## À faire

- Finaliser le dépôt Git du projet avec l'ensemble de la documentation, des schémas et des codes sources pour la clôture de la formation.

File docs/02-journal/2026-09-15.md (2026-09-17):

# Journal du mardi 15 septembre 2026 (rédigé par : Komnakan YOMBOU)

## Fait aujourd'hui

- **Ajustement de l'architecture matérielle (Consigne de formation)** : 
  - Rappel des formateurs : utilisation obligatoire de l'**ESP32** (abandon des cartes Arduino Uno et Nano).
  - Retour au module **ESP32 DevKit** pour piloter le système.
- **Réadaptation du montage et nouveaux composants** :
  - Reprise complète du câblage sur breadboard en associant l'ESP32 DevKit au driver moteur **TB6612FNG** et au capteur à ultrasons.
  - Intégration d'un récepteur et d'une **télécommande infrarouge** (remplacement des capteurs suiveurs de ligne initiaux) pour permettre le contrôle du robot en mode manuel (pilotage par télécommande) et en mode automatique.
- **Tests et Validation** :
  - Réalisation des tests fonctionnels complets : la communication et les commandes répondent parfaitement.
- **Illustrations et Vidéos** :
  - Intégration de la photo du montage finalisé avec l'ESP32 DevKit et la télécommande : 
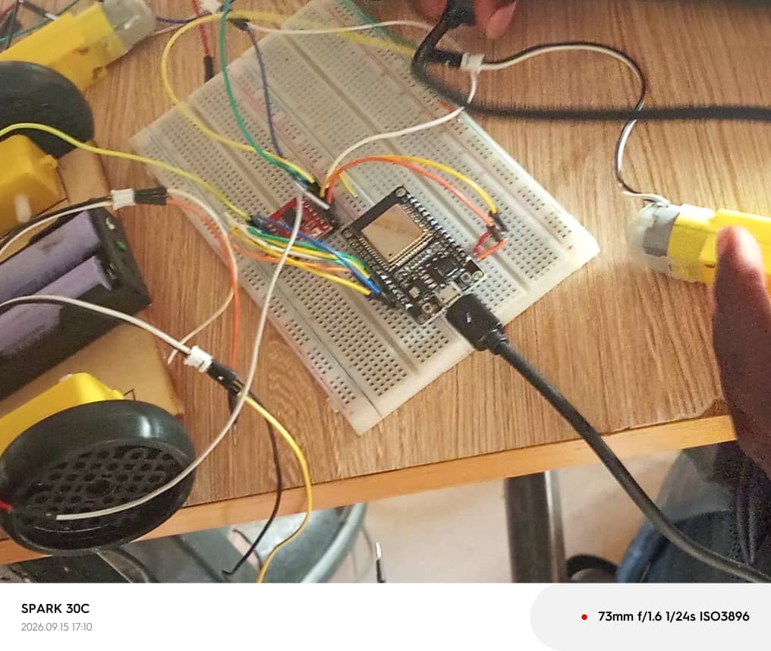
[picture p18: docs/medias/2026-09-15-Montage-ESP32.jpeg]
Montage final avec ESP32 DevKit, driver TB6612FNG et télécommande IR
    
  - Intégration du lien vers le compte Google Drive contenant les vidéos de démonstration des modes manuel et automatique :
    [Lien Google Drive - Démonstration du robot (Modes Manuel & Auto)](https://drive.google.com/drive/folders/1oa1c9F_DsdXSloXRziNlXWKfMwQ8xHTm?usp=sharing)

## Appris

- L'importance de respecter scrupuleusement les contraintes techniques et pédagogiques imposées par le cahier des charges de la formation (utilisation exclusive de l'ESP32).
- L'implémentation d'une interface de commande infrarouge pour basculer dynamiquement entre un mode de conduite manuel et un mode autonome.

## Raté, puis corrigé

- **Contrainte** : Incompatibilité avec l'utilisation des cartes Arduino imposée par le cadre de la formation -> **Corrigé** : Reprise et adaptation réussie du schéma de câblage pour migrer l'ensemble du système sur l'ESP32 DevKit tout en conservant le driver TB6612FNG.

## Décidé

- Valider définitivement l'ESP32 DevKit, le driver TB6612FNG, le capteur ultrason et la télécommande infrarouge comme socle matériel et fonctionnel du robot éducatif.

## À faire

- Finaliser la rédaction de la documentation technique globale du projet et préparer la soutenance ainsi que la démonstration finale.

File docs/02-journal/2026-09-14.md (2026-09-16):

# Journal du lundi 14 septembre 2026 (rédigé par : Komnakan YOMBOU)

## Fait aujourd'hui

- **Évolution de la conception matérielle** : 
  - Abandon du volumineux driver moteur précédent au profit du driver **TB6612FNG** (plus compact et parfaitement adapté au montage).
  - Migration de la carte de commande vers l'**Arduino Nano**, offrant un encombrement réduit et une meilleure intégration physique.
- **Assemblage et Tests fonctionnels** :
  - Réalisation complète du nouveau câblage sur breadboard avec l'Arduino Nano et le driver TB6612FNG.
  - Test et validation de la carte Arduino Nano (fonctionnement nominal).
  - Test et validation des moteurs DC branchés sur le driver.
  - Test et validation du capteur à ultrasons : tout fonctionne parfaitement et sans encombre.
- **Illustrations et Démonstration** :
  - Intégration de la photo du montage réussi :
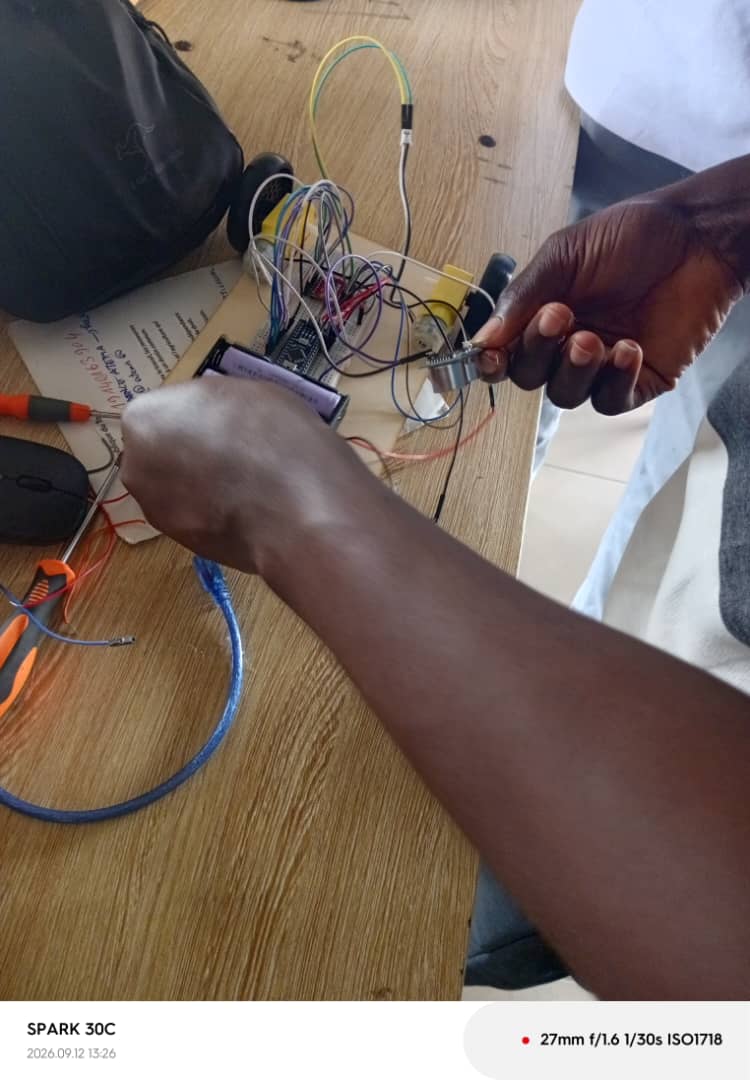
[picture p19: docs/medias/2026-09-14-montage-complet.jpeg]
Montage réussi avec l'Arduino Nano et le driver TB6612FNG
    
  - Intégration du lien vers la vidéo de démonstration du robot en action :
    [Lien Google Drive - Robot en action](https://drive.google.com/drive/folders/1oa1c9F_DsdXSloXRziNlXWKfMwQ8xHTm?usp=sharing)

## Appris

- L'importance d'utiliser des composants aux dimensions adaptées (comme le driver TB6612FNG et l'Arduino Nano) pour éviter les problèmes d'intégration physique sur plaque d'essai et sécuriser le montage électronique.
- La robustesse de la nouvelle configuration matérielle validée lors des tests combinés (moteurs + ultrasons).

## Raté, puis corrigé

- Problèmes d'encombrement et d'instabilité des composants précédents -> résolus par le remplacement de l'Arduino Uno par l'Arduino Nano et l'adoption du driver TB6612FNG, garantissant un montage propre et fonctionnel.

## Décidé

- Conserver l'Arduino Nano et le driver TB6612FNG comme architecture matérielle officielle et définitive pour le reste du projet de robot éducatif.

## À faire demain

- Poursuivre l'intégration des autres capteurs (infrarouges, microphone, buzzer) et préparer l'écriture du programme global de déplacement autonome.

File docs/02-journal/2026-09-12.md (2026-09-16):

# Journal du samedi 12 septembre 2026 (rédigé par : Komnakan YOMBOU)

## Fait aujourd'hui

- **Travaux sur le projet (Robot éducatif)** : 
  - Migration de la plateforme de commande : utilisation de la carte **Arduino** et du driver moteur de puissance (type L296B / L298N) en raison des contraintes d'encombrement et de support par rapport à l'ESP32.
  - Réalisation du montage physique : superposition du driver moteur sur la carte Arduino, raccordement des moteurs DC et de l'alimentation externe.
  - **Incident critique** : lors du branchement à la machine et du lancement du programme, une surtension/court-circuit a provoqué l'extinction immédiate du PC, endommageant la carte mère et la puce Super I/O (nécessitant le remplacement de la carte mère).
  - Après sécurisation et vérification, reprise et finalisation réussie du câblage et du pilotage du driver moteur.
  - Intégration des photos du montage :
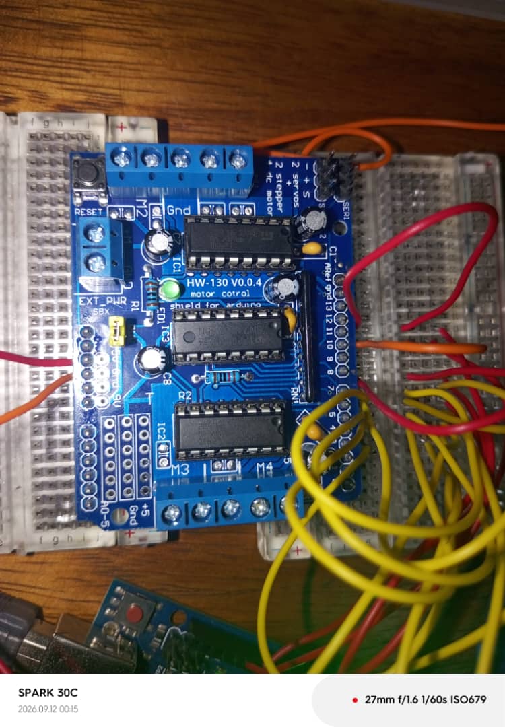
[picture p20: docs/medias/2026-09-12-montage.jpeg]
Montage du driver moteur sur la carte Arduino
    
## Appris

- L'importance cruciale de la sécurité électrique et de l'isolation des alimentations de puissance (moteurs) par rapport à l'alimentation logique reliée par port USB à l'ordinateur, afin d'éviter tout retour de tension destructeur pour le matériel informatique.
- La gestion des contraintes d'encombrement physique des composants de puissance (drivers moteurs volumineux) sur les plaques d'essai.

## Raté, puis corrigé

- **Raté** : Court-circuit / retour de tension vers le port USB lors du test initial du driver moteur, entraînant la détérioration de la puce Super I/O et de la carte mère du PC.
- **Corrigé** : Remplacement de la carte mère de l'ordinateur, révision complète du schéma de câblage pour séparer proprement les masses et l'alimentation de puissance, puis validation réussie du fonctionnement du driver moteur.

## Décidé

- Redoubler de vigilance lors des phases de test impliquant de la puissance (moteurs) connectée en même temps à l'ordinateur.

## À faire

- Poursuivre les tests de mouvement du robot et préparer les prochaines étapes de l'intégration logicielle.

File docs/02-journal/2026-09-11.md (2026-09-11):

# Journal du vendredi 11 septembre 2026 (rédigé par : Komnakan YOMBOU)

## Fait aujourd'hui

- **Travaux sur le projet & Tests matériels** : 
  - Réception de l'intégralité du matériel pour le robot éducatif.
  - Poursuite des tests de composants :
    - Souci de communication rencontré entre l'écran LCD et l'ESP32 -> remplacement temporaire par l'écran OLED en attendant de se pencher à nouveau sur le LCD lors du montage final.
    - Problème d'insertion du driver moteur (mentionné L296D) sur la breadboard (problème d'espacement des broches) -> superposition temporaire avec l'Arduino UNO pour stabiliser le montage.
  - Évaluation d'une migration potentielle de l'ESP32 vers l'Arduino UNO pour simplifier les connexions et la compatibilité des composants.
  - Réalisation et validation des tests pratiques :
    - Test de la carte Arduino :
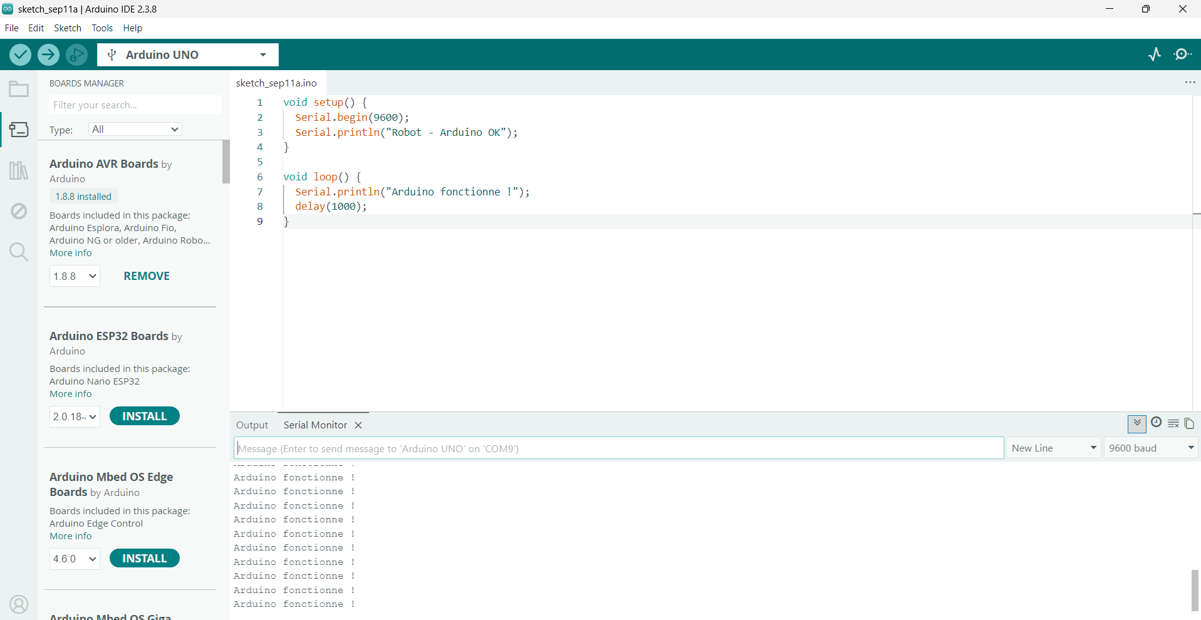
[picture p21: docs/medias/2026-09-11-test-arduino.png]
Test de la carte Arduino
      
    - Test du capteur à ultrasons :
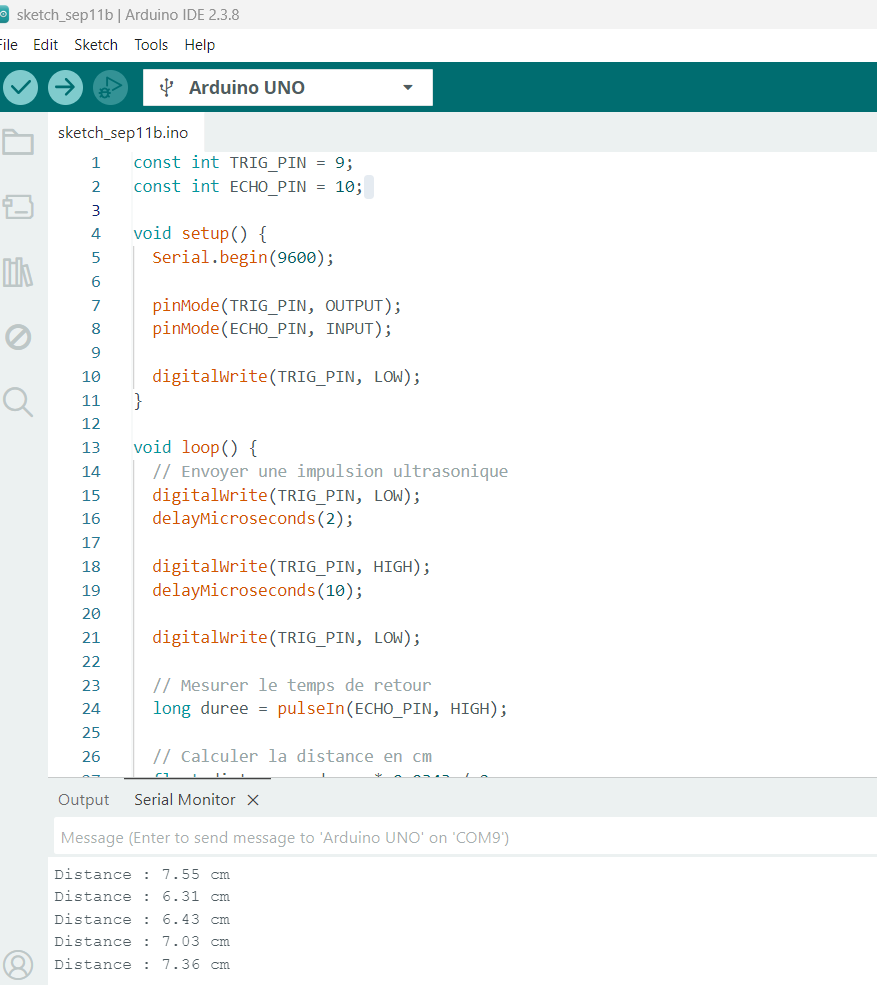
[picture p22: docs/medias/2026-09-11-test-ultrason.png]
Test du capteur à ultrasons
      

## Appris

- L'importance de valider la compatibilité physique (breadboard et brochage) des composants de puissance comme les drivers moteurs dès leur réception.
- La flexibilité nécessaire dans le choix des microcontrôleurs et des afficheurs (OLED vs LCD) face aux contraintes de câblage et de communication rencontrées en cours de route.

## Raté, puis corrigé

- Problème de communication I2C/broches avec le LCD -> contourné par l'utilisation de l'OLED.
- Incompatibilité physique du driver moteur sur la breadboard -> solution temporaire par superposition sur Arduino UNO et réflexion sur le choix final de la carte de commande.

## Décidé

- Stabiliser le choix de la carte de contrôle (arbitrage final entre ESP32 et Arduino UNO) et valider le montage électronique global avec les capteurs opérationnels.

## À faire

- Poursuivre les tests d'intégration et finaliser la structure logicielle du robot.

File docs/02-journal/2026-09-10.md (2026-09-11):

# Journal du jeudi 10 septembre 2026 (rédigé par : Komnakan YOMBOU)

## Fait aujourd'hui

- **Travaux sur le projet (Robot éducatif)** : 
  - Finalisation complète du câblage de notre circuit sur **Fritzing** :
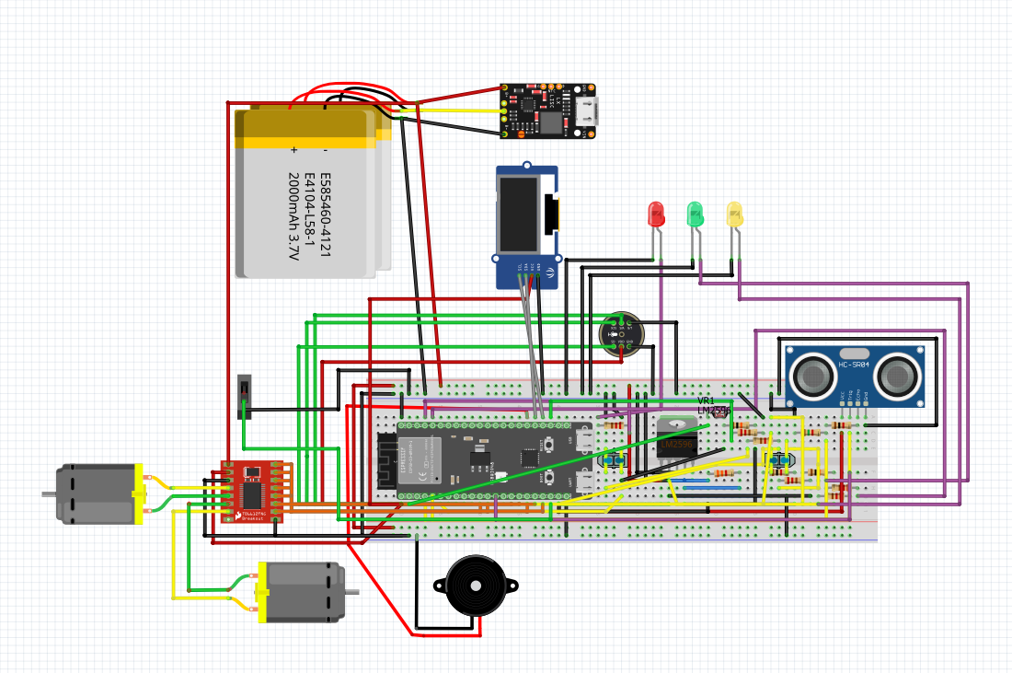
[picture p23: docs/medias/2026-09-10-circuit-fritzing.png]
Câblage du circuit réalisé dans Fritzing
    
  - Constat des limites de Fritzing (absence de module de simulation dynamique pour notre montage), entraînant la décision de reprendre rapidement le circuit sous **Proteus** pour effectuer la simulation.
- **Tests matériels** :
  - Réception d'une partie des composants de notre nomenclature.
  - Réalisation de tests de bon fonctionnement et de vérification de l'état des éléments reçus (écran LCD, LEDs, carte XIAO ESP32-S3, etc.) : 
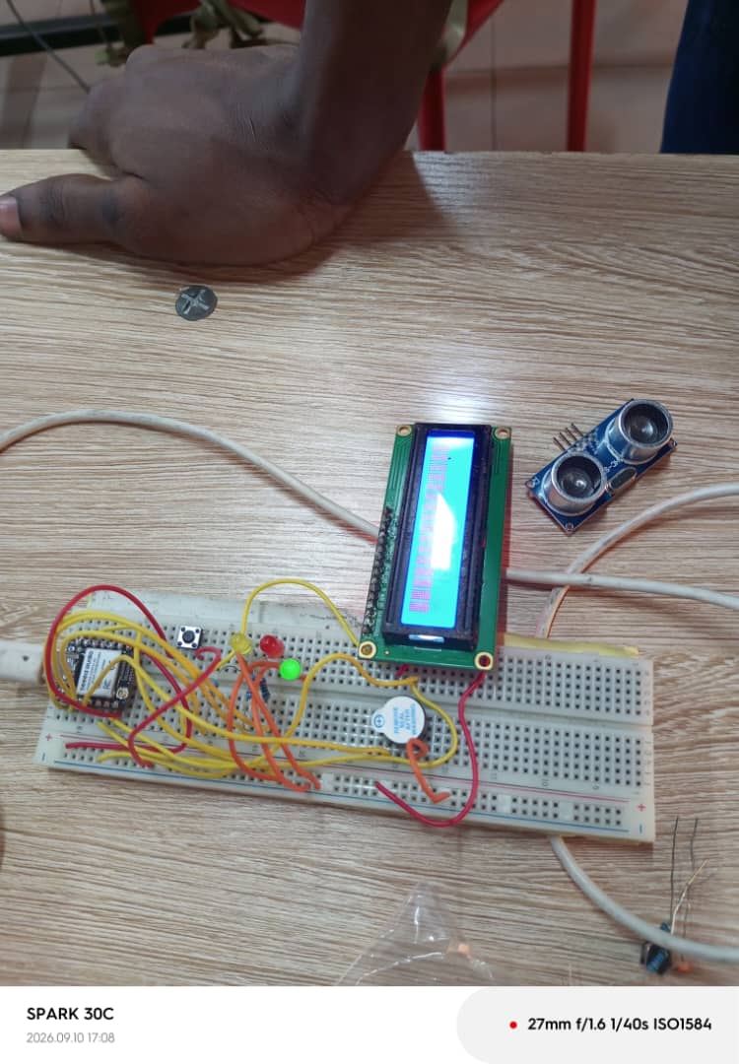
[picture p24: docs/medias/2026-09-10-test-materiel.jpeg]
Test du Matériel
     

## Appris

- L'importance de choisir le bon outil de simulation selon les besoins fonctionnels (Fritzing pour la schématisation et le câblage visuel, Proteus pour la simulation logique et comportementale).
- La nécessité de tester systématiquement les composants reçus avant l'assemblage final pour anticiper toute défaillance matérielle.

## Raté, puis corrigé

- Impossibilité de simuler le comportement du circuit sous Fritzing -> correction : planification d'une reprise du schéma sous Proteus.

## Décidé

- Migrer la simulation sous Proteus pour valider le comportement logique de notre montage électronique.

## À faire demain

- Poursuivre la simulation sous Proteus et entamer l'assemblage physique des premiers modules testés.

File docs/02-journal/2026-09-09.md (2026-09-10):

# Journal du mercredi 9 septembre 2026 (rédigé par : Komnakan YOMBOU)

## Fait aujourd'hui

- **Mini-projet KiCad (Allumage de LEDs)** : 
  - Réalisation de la saisie schématique pour un circuit de commande de LEDs.
  - Importation de bibliothèques spécifiques, telles que celle de la carte XIAO.
  - Création personnalisée de nouveaux symboles et de nouveaux composants.
  - Assignation des empreintes (footprints) correspondantes aux composants du circuit.
- **Programmation (Thonny)** :
  - Transition vers l'environnement de développement Thonny pour entamer la programmation et le pilotage du dispositif.

## Appris

- La maîtrise de la création de composants et de symboles personnalisés sur KiCad lorsque ceux-ci ne sont pas présents dans les bibliothèques standard.
- L'intégration de modules spécifiques comme le XIAO dans un projet de conception de carte électronique.
- L'association entre le schéma logique sous KiCad et le code de contrôle exécuté via Thonny.

## Raté, puis corrigé

- Ajustement lors de la création des nouveaux symboles et de l'assignation des empreintes pour s'assurer de la parfaite correspondance physique sur le futur PCB.

## Décidé

- Consolider les compétences acquises sur KiCad pour finaliser le design de notre propre carte d'interface pour le robot éducatif.

## À faire demain

- Poursuivre les tests de programmation sous Thonny et avancer sur la documentation globale du projet.

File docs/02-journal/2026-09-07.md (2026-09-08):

# Journal du lundi 7 septembre 2026 (rédigé par : Komnakan YOMBOU)

## Fait aujourd'hui

- **Cours d'initiation au PCB** : 
  - Session théorique sur les principes de conception des circuits imprimés, les règles de routage et l'importance des empreintes.
- **Réalisation d'un interrupteur crépusculaire sous KiCad** :
  - Conception et dessin du schéma synoptique / schématique du circuit de l'interrupteur crépusculaire :
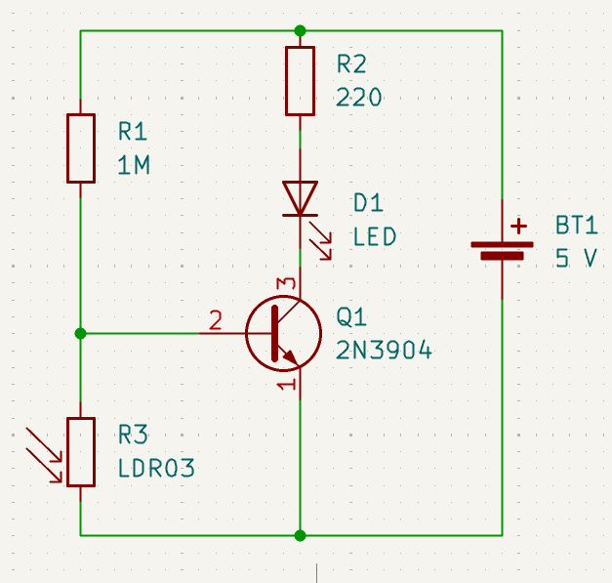
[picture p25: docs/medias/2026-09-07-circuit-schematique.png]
Schéma schématique de l'interrupteur crépusculaire
    
  - Passage à l'éditeur PCB et placement des composants :
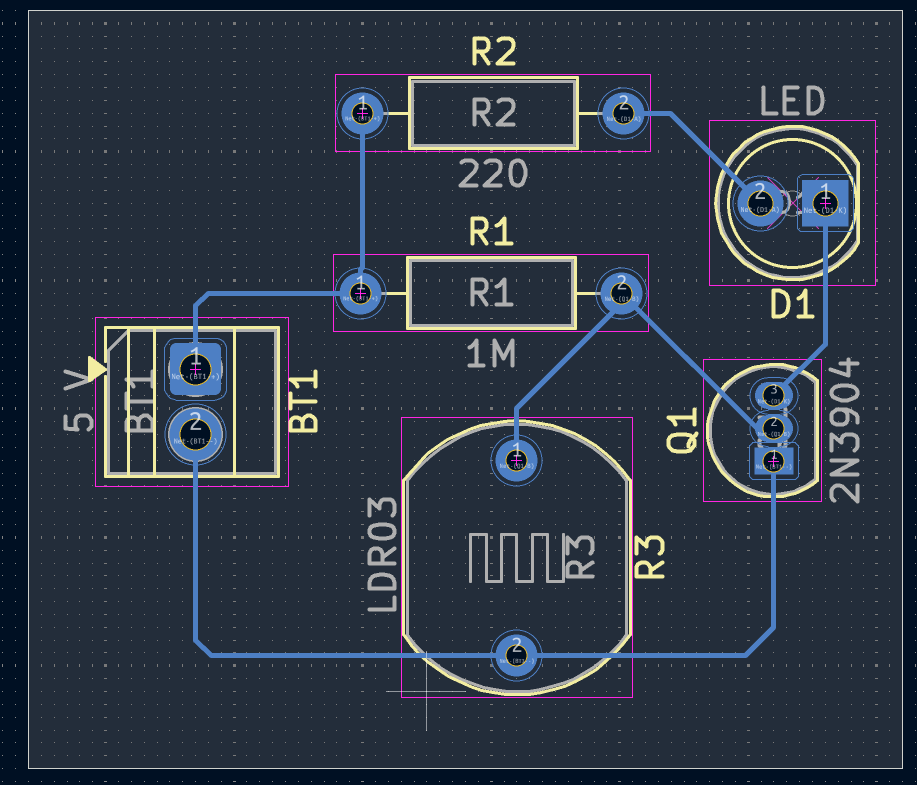
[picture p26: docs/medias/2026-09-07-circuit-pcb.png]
Éditeur PCB - Placement des composants
    
  - Routage et connexion des pistes électriques :
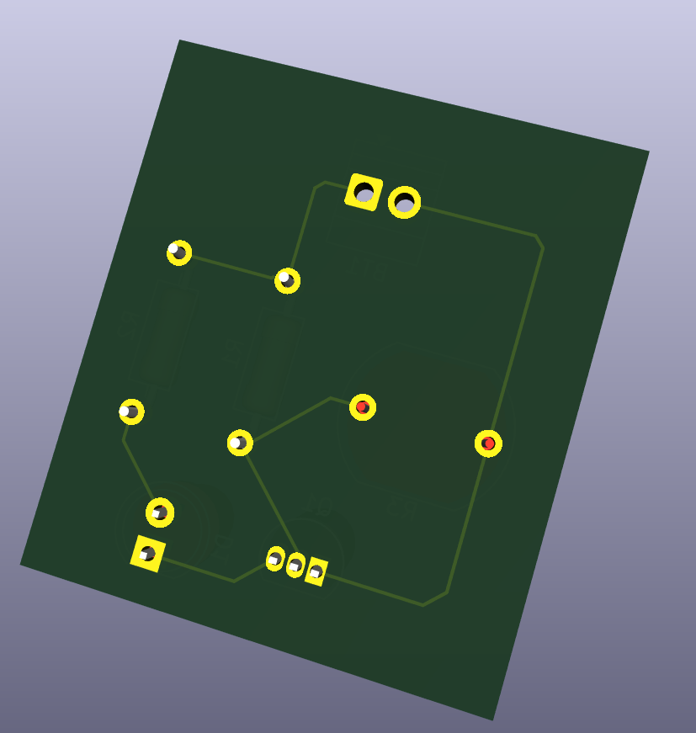
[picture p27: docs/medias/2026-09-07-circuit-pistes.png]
Pistes connectées du circuit imprimé
    
  - Génération et vérification de la visualisation en 3D de la carte finie :
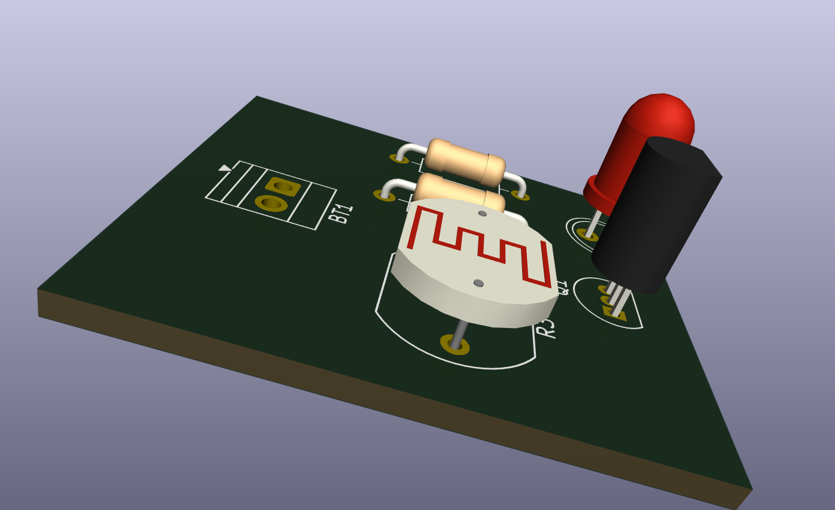
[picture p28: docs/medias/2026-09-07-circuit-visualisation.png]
Visualisation 3D de l'interrupteur crépusculaire
    

## Appris

- La méthodologie complète de conception de circuits imprimés sous **KiCad**, depuis la saisie schématique jusqu'au routage des pistes.
- L'association indispensable entre les symboles schématiques et leurs empreintes physiques (footprints) pour éviter les erreurs de fabrication.
- L'utilisation du rendu 3D pour valider l'encombrement et l'aspect visuel de la carte avant sa production.

## Raté, puis corrigé

- Ajustement de certaines largeurs de pistes et de l'espacement (dégagement) lors du routage pour respecter les règles de l'art de la fabrication de PCB.

## Décidé

- Utiliser KiCad pour la conception de notre future carte d'interface dédiée à notre projet de robot éducatif.

## À faire demain

- Poursuivre l'exploration des outils de CAO électronique et préparer l'intégration des schémas pour le robot.

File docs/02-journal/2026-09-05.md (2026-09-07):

# Journal du samedi 5 septembre 2026 (rédigé par : Komnakan YOMBOU)

## Fait aujourd'hui

- **Projet Station Météorologique** : 
  - Réalisation du montage électronique sur la plaque d'essai (breadboard SK10).
  - Intégration et câblage des composants suivants : la carte **ESP32-S3**, le capteur de température et d'humidité **DHT11**, et un écran **OLED**.
  - Intégration de deux photos illustrant le montage et le système en fonctionnement :
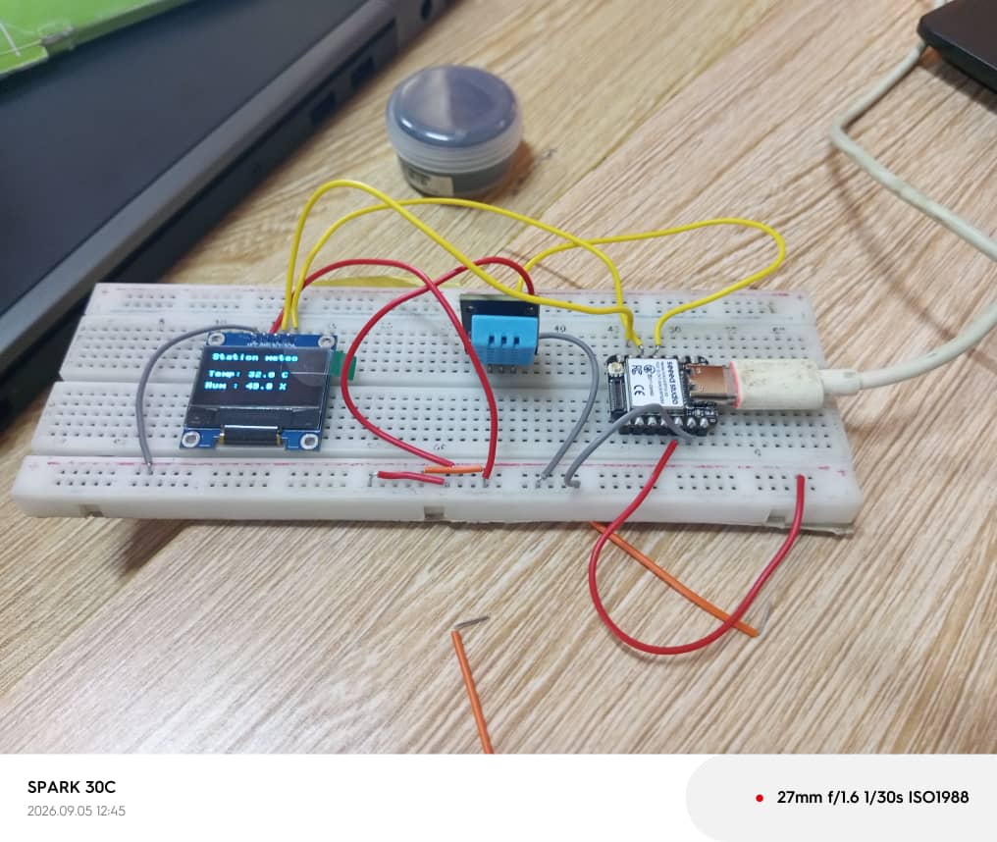
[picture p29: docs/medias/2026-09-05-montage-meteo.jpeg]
Montage sur breadboard SK10 (ESP32-S3, DHT11, OLED)
    

- **Programmation (MicroPython / Thonny)** :
  - Écriture et téléversement du code en **MicroPython** à l'aide de l'IDE **Thonny** pour initialiser l'ESP32-S3, lire les valeurs du capteur DHT11 et les afficher en temps réel sur l'écran OLED :
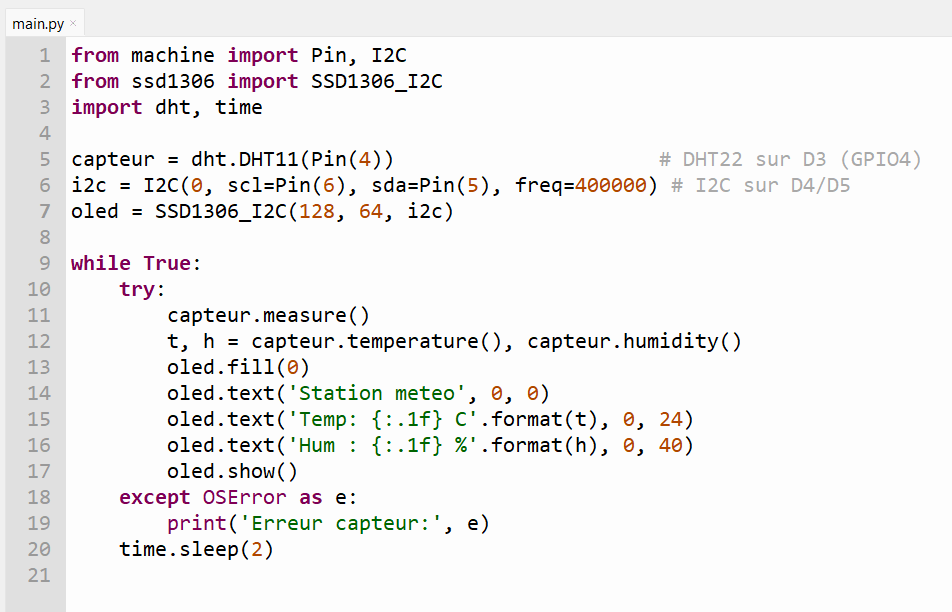
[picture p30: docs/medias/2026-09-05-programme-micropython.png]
Programme MicroPython
    

## Appris

- La mise en œuvre de scripts en MicroPython pour communiquer avec des capteurs numériques (DHT11) et un écran I2C (OLED) depuis une carte ESP32-S3.
- L'utilisation rigoureuse de la breadboard SK10 pour organiser le câblage d'un système embarqué multi-composants.

## Raté, puis corrigé

- Suite à une première absence d'affichage, nous avons relier les blocs d'alimentation par un pont.

## Décidé

- Valider ce montage comme base fonctionnelle pour l'acquisition et l'affichage de données environnementales.

## À faire

- Poursuivre l'intégration des fonctionnalités et préparer les prochaines étapes du projet.

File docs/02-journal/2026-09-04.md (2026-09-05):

# Journal du vendredi 4 septembre 2026 (rédigé par : Komnakan YOMBOU)

## Fait aujourd'hui

- **Modélisation 3D (Fusion 360)** : 
  - Modélisation de deux corps distincts en utilisant des fonctionnalités avancées telles que la projection d'esquisse, l'extrusion et l'utilisation de plans de construction (plan milieu).
  - Intégration de deux visuels de la modélisation à deux corps :
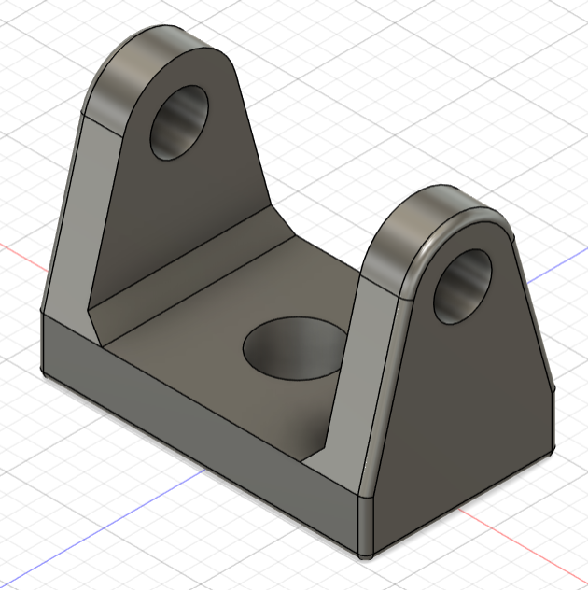
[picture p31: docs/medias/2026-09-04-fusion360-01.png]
Modélisation multi-corps - Vue 1
    
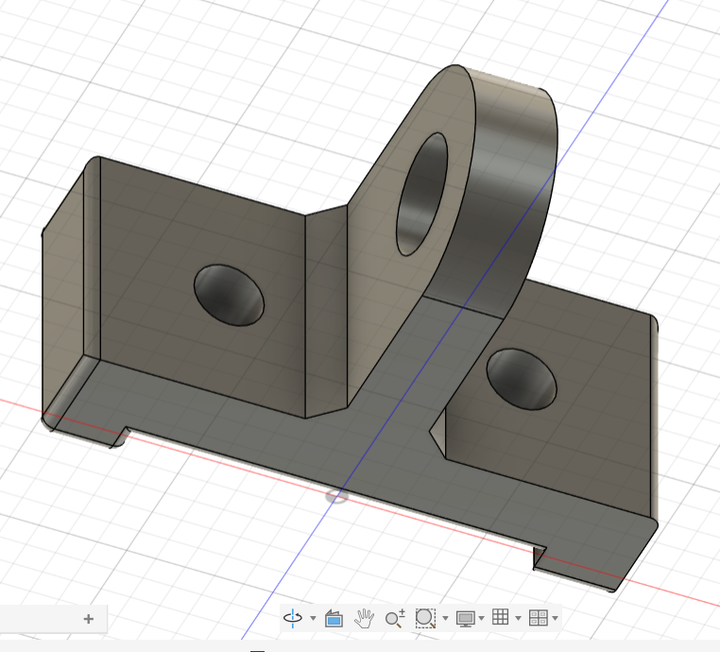
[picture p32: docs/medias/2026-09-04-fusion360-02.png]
Modélisation multi-corps - Vue 2
    
  - Récupération de l'exercice pratique assigné à faire à la maison :
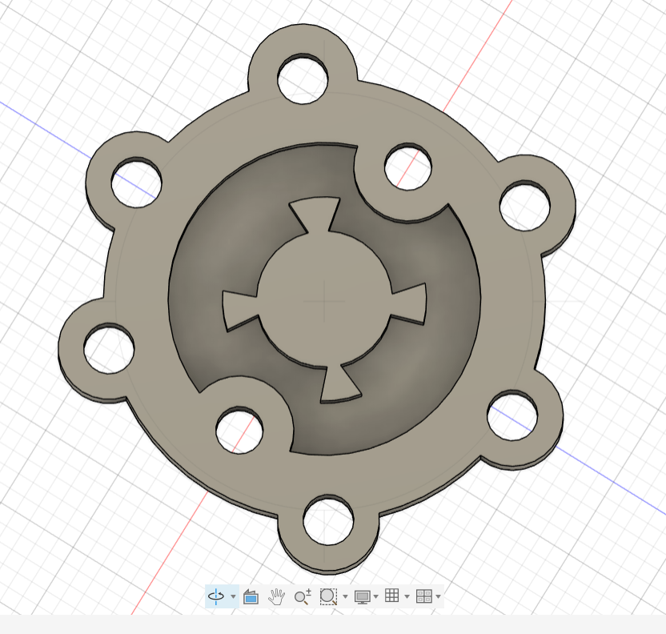
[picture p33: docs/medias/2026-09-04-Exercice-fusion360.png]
Exercice de modélisation à la maison
    

- **Fabrication de PCB (Électronique)** :
  - Étude théorique des différentes techniques de fabrication de circuits imprimés (PCB).
  - Réalisation pratique de l'impression d'un PCB en utilisant la machine **F2 Ultra**.
  - Intégration de la photo du PCB réalisé :
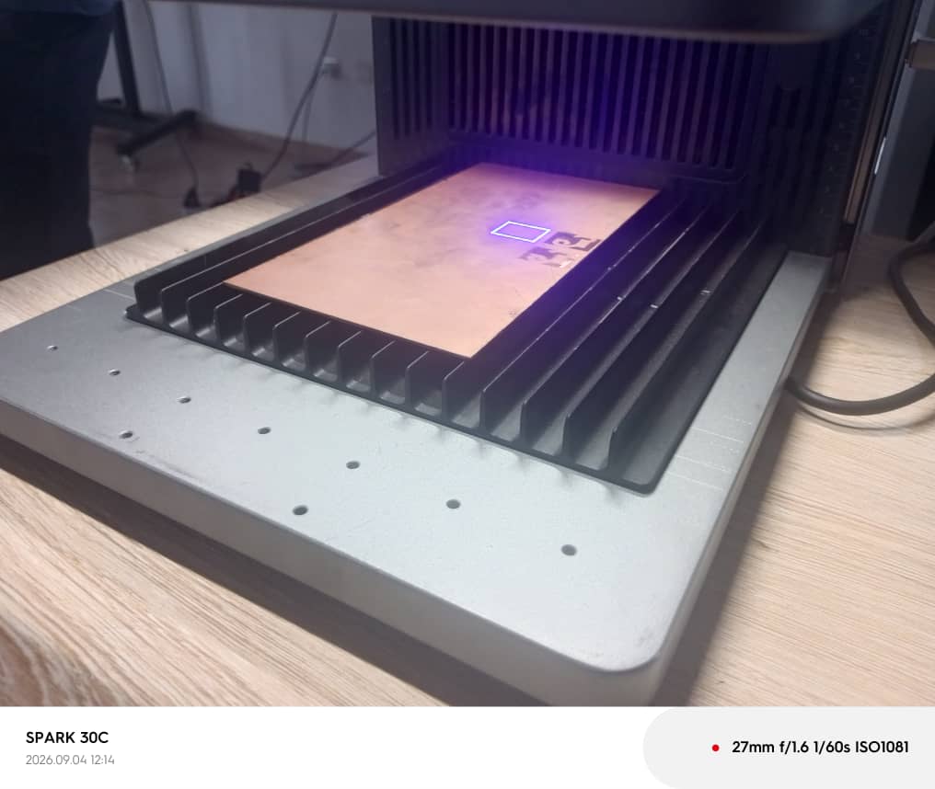
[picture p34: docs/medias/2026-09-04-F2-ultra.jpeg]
Impression du PCB avec la F2 Ultra
    

- **Programmation Python (Thonny)** :
  - Poursuite de l'apprentissage de la programmation en Python avec l'étude des structures conditionnelles (`if`, `elif`, `else`) et des boucles (`for`, `while`), indispensables pour la future logique de contrôle du robot éducatif.

## Appris

- La maîtrise des outils de construction géométrique (plan milieu, projection) sous Fusion 360 pour concevoir des assemblages et des pièces complexes à plusieurs corps.
- Les procédés industriels et de prototypage rapide pour la fabrication de circuits imprimés (PCB) à l'aide de la F2 Ultra.
- L'implémentation de la logique algorithmique (conditions et boucles) en Python pour préparer l'automatisation des comportements du robot.

## Raté, puis corrigé

- Ajustement des paramètres de projection et de positionnement des plans de construction sur Fusion 360 pour éviter les erreurs de référence géométrique entre les deux corps.

## Décidé

- Appliquer les techniques de modélisation multi-corps pour la conception personnalisée du châssis et des supports de capteurs de notre robot éducatif.
- Programmer notre Robot en Python.
## À faire demain

- Correction de l'exercice à domicile sur Fusion 360 et préparer la mise en pratique du code Python pour les interactions matérielles.

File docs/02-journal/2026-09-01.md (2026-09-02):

# Journal du mardi 1er septembre 2026 (rédigé par : Komnakan YOMBOU)

## Fait aujourd'hui

- Modélisation dans Fusion 360 : réalisation d'un cylindre par trois méthodes différentes (révolution d'un profil, extrusion d'un cercle, et forme primitive cylindre directement disponible dans la bibliothèque de formes)

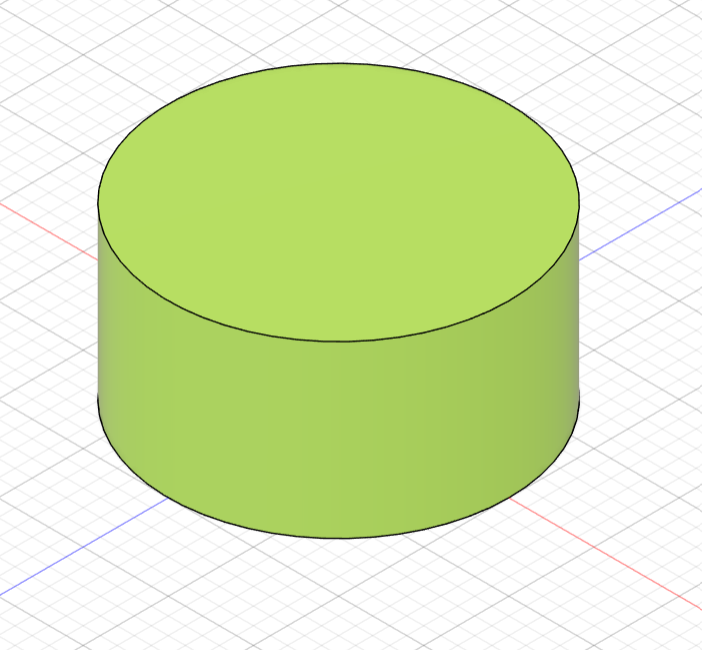
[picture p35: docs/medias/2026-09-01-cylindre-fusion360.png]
Modélisation du porte-clé dans Fusion 360 — vue 1
  
  
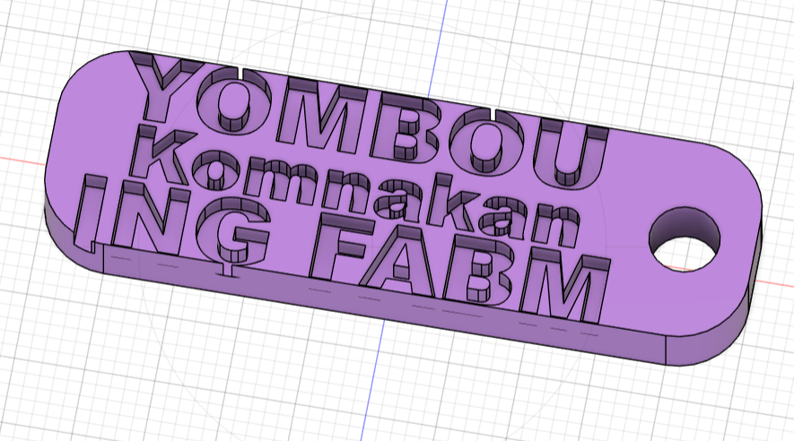
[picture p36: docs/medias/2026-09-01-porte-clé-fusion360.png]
Modélisation du porte-clé dans Fusion 360 — vue 4
  
- Impression DTF avec XTools, via l'appareil « Printer »
  Impression DTF réalisée avec XTools
  Impression DTF réalisée avec XTools
  Impression DTF réalisée avec XTools
- Montage de circuits électroniques simples sur breadboard SK01, dans le but de se familiariser avec la plaque d'essai
  Circuit simple monté sur breadboard SK01

## Appris

- Une même forme (le cylindre) peut être obtenue par plusieurs méthodes de modélisation dans Fusion 360 : révolution d'un profil 2D, extrusion d'une esquisse, ou forme primitive préconstruite — chaque méthode a ses cas d'usage selon la complexité de la pièce visée
- Le fonctionnement de l'impression DTF sous XTools via l'appareil Printer
- La prise en main du breadboard SK01 pour monter rapidement un circuit sans soudure

## Raté, puis corrigé

## Décidé

- Pour l'impression DTF, nous avons décidé de prendre une image avec les dimensions <= 100 pour une impression plus rapide et plus fluide.

## À faire demain

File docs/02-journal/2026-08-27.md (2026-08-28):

# Journal du jeudi 27 août 2026 (rédigé par : Komnakan YOMBOU)

## Fait aujourd'hui

- Atelier « Découpe laser » : modélisation d'une carte de visite dans XTools, dimensions 85 mm (longueur) × 55 mm (largeur)
- Paramétrage de la découpeuse laser P3 : texte → puissance 20, vitesse 600 mm/s ; contours → puissance 90, vitesse 50 mm/s
  Découpeuse Laser P3
  Carte de visite modélisée dans XTools
- Atelier « Électronique » : présentation du CyberPi et de l'écosystème mBuild, généralités et capteurs
- Installation du logiciel mBlock ; programmation de l'allumage des LED du CyberPi au démarrage
- Programmation de l'allumage de toutes les LED du CyberPi
  Toutes les LED du CyberPi allumées
- Programmation d'un jeu de lumière avec allumage séquentiel par ordre régulier
  Jeu de lumière séquentiel sur le CyberPi
- Programmation d'un feu tricolore : vert 5 s, orange 2 s, rouge 7 s
  Feu tricolore programmé sur le CyberPi
- Programmation de la détection de luminosité environnante via le capteur de lumière : 0 = absence totale de luminosité, 100 = forte luminosité (testé en journée)
  Capteur de lumière du CyberPi en fonctionnement
- Atelier « Impression 3D » : paramètres clés d'une bonne impression (remplissage/infill, parois, couches supérieures et inférieures)
- Installation et prise en main de Bambu Studio ; import d'un fichier cube, simulation puis impression
  Simulation du cube dans Bambu Studio
  Cube en cours d'impression 3D
  Cube imprimé en 3D

## Appris

- L'influence de la puissance et de la vitesse laser selon qu'on découpe (contours) ou qu'on grave/marque (texte) : puissance haute + vitesse basse pour couper franchement, puissance basse + vitesse haute pour un rendu plus fin
- La logique de programmation par blocs sous mBlock pour piloter les LED et capteurs du CyberPi
- Les paramètres de tranchage qui conditionnent la qualité d'une impression 3D : infill, parois, couches supérieures/inférieures

## Raté, puis corrigé
- Lors de la pemière programmation du feu tricolore, noous n'avons pas obtenu un cycle continu. Dès que le dispositif fini d'allumer les 3 feux, elle s'éteint. Dans contrôle, nous avons ajouté le pour toujours et ainsi nous avons obtenu un cycle à repétition infinie.

## Décidé
Pour configurer une découpe laser :
- Gravure : Puissance 20 et vitesse 600 mm/s
- Découpage : Puissance 90 et vitesse 50 mm/s

## À faire demain

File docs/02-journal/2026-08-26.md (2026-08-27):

# Journal du mercredi 26 août 2026 (rédigé par : Komnakan YOMBOU)

## Fait aujourd'hui

- Constitution des groupes de travail ; affectation au groupe 04
- Atelier « Formation technique — Fabrication numérique / Fabrication additive » : introduction à la fabrication additive, historique de l'impression 3D, grandes familles de technologies, tableau comparatif des technologies
- Atelier « Gestion de projet » : présentation du projet de fin de formation et des critères de choix (priorité à un projet à but éducatif, répondant à un problème majeur de l'éducation)
- Atelier « Technologie découpe laser » : anatomie d'une découpeuse laser, grandes familles de lasers industriels ; installation du logiciel XTools ; envoi d'un texte à la machine et découpe réussie sur une planche
  Découpe laser réalisée avec le prénom Sitou
- Atelier « Bases de l'électronique dans les FabLabs » : grandeurs électriques de base, symboles physiques ; mesure de la tension de 2 piles ; mesure de la résistance de 3 résistances ; code couleur des résistances

## Appris

- Les grandes familles de technologies de fabrication additive et leurs différences, via le tableau comparatif
- Le fonctionnement général d'une découpeuse laser et l'usage du logiciel XTools pour envoyer un fichier à la machine
- Comment lire un code couleur de résistance pour en déduire la valeur, et comment cette valeur théorique se compare à une mesure au multimètre

## Raté, puis corrigé

## Décidé

- Pour la mesure de tension, nous avons fait la mesure sur deux piles : une pile noire et une pile verte. Pour le noir, nous avons trouvé une tension de 0,809 V et 1,544 V pour la verte. Nous avons conclu que la noire est déchargée et aussi qu'il existe les incertitudes lors des mesures puisque pour une même pile, nous avons plusieurs valeurs mais qui sont proches.

## À faire demain

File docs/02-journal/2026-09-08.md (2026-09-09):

# Journal du mardi 8 septembre 2026 (rédigé par : Komnakan YOMBOU)

## Fait aujourd'hui

- **Travaux sur le projet (Robot éducatif)** : 
  - Tentative de simulation du circuit électronique sous **Wokwi**. Face aux limitations rencontrées sur cette plateforme, bascule et poursuite de la simulation sous **Fritzing** pour affiner le câblage.
- **Cours CAO et FAO** : 
  - Suivi du module sur la Conception Assistée par Ordinateur (CAO) et la Fabrication Assistée par Ordinateur (FAO) : de la conception numérique à la pièce usinée en passant par les parcours d'outils sous **Fusion 360**.
  - Intégration des deux photos illustrant la pièce simulée et la pièce usinée (fraisée) sous Fusion 360 :
    Pièce simulée dans Fusion 360
    Pièce usinée et fraisée dans Fusion 360

## Appris

- L'adaptation des outils de simulation selon leur complexité et leurs limites (utilisation de Fritzing comme alternative pour la représentation et le câblage des composants).
- Le processus complet de FAO sous Fusion 360, permettant de générer les trajectoires d'usinage (fraisage) à partir d'un modèle 3D tout en respectant les contraintes de fabrication.

## Raté, puis corrigé

- Limitations techniques de Wokwi pour la prise en charge de certains modules spécifiques du robot -> contourné par l'utilisation de Fritzing pour valider le schéma de câblage.

## Décidé

- Structurer les schémas de câblage définitifs sous Fritzing et exploiter Fusion 360 pour la FAO des pièces mécaniques du robot.

## À faire demain

- Poursuivre la mise en œuvre des étapes du projet et la préparation de la documentation technique.

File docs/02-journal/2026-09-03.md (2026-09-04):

# Journal du jeudi 3 septembre 2026 (rédigé par : Komnakan YOMBOU)

## Fait aujourd'hui

- **Gestion de projet** : Travail approfondi sur la nomenclature et validation de la liste définitive des composants pour le robot éducatif (intégration de l'ESP32-S3, des capteurs, de l'écran, du microphone et du buzzer avec leurs marges de rechange).
- **Atelier de programmation (Thonny / Python)** : 
  - Initiation et pratique de la programmation en Python à l'aide du logiciel Thonny.
  - Étude détaillée de la syntaxe de base en Python, de la manipulation des listes, des tuples et des structures de données essentielles.

## Appris

- La structuration des données en Python (listes et tuples) qui facilitera la gestion des états des capteurs et des séquences de déplacement du robot.
- L'utilisation de l'IDE Thonny comme environnement de développement léger et adapté pour tester rapidement du code.

## Raté, puis corrigé

- Aucun incident technique à signaler lors des manipulations logicielles.

## Décidé

- Validation définitive de la liste des composants matériels pour passer aux phases d'approvisionnement et de montage.
- Utilisation des notions de programmation Python apprises pour préparer l'écriture des scripts de test des capteurs.

## À faire demain

- Poursuivre la conception mécanique des supports de capteurs, le châssis, le boîtier sous Fusion 360 et préparer l'intégration logicielle sur l'environnement de développement.

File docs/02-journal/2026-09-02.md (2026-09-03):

# Journal du mercredi 2 septembre 2026 (rédigé par : Komnakan YOMBOU)

## Fait aujourd'hui

- Atelier « Gestion de projet » : revue du modèle V0 du robot, avec révision des composants retenus et des fonctionnalités prévues
- Atelier « Algorithmique » : présentation et discussion des notions d'algorithmique
- Montage et programmation d'un robot mBot, avec contournement d'obstacles grâce au capteur à ultrasons
  Montage du robot mBot
  Fin de Montage du robot mBot
  Programme du Robot mbot

## Appris

- La démarche de revue de projet : confronter le modèle V0 prévu aux composants et fonctionnalités réellement disponibles, et ajuster si besoin avant de poursuivre
- Des notions d'algorithmique appliquées à la prise de décision d'un robot (condition, boucle de contrôle)
- La prise en main du robot mBot et de la logique de contournement d'obstacle à partir d'un capteur à ultrasons — directement transposable au capteur HC-SR04 prévu pour le robot de l'équipe

## Raté, puis corrigé

## Décidé

- Pour l'avancée du robot, nous avons programmé le motor du robot sur 50 trs/min.

## À faire demain

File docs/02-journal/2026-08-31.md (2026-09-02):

# Journal du lundi 31 août 2026 (rédigé par : Komnakan YOMBOU)

## Fait aujourd'hui

- Réorientation du projet de fin de formation : abandon de l'indicateur sonore au profit d'un **Robot éducatif** intelligent et modulaire.
- Établissement de la nomenclature complète et sécurisée des composants du robot (incluant ESP32-S3, châssis 2 roues, driver moteur, capteurs IR, capteur ultrason HC-SR04, microphone numérique, écran OLED, capteur de lumière, buzzer et éléments de câblage avec marges de rechange).
- Atelier de conception 3D : modélisation d'un cube de référence dans Fusion 360 en vue des futures impressions de pièces pour le châssis et les supports de capteurs.
  Modélisation d'un cube dans Fusion 360

## Appris

- L'importance de redéfinir un cahier des charges clair et validé lors d'un changement de sujet en cours de formation, en veillant à conserver la complexité technique requise (multiples capteurs, actionneurs et procédés de fabrication).
- La prise en main de l'environnement de modélisation 3D de Fusion 360 pour concevoir des géométries paramétriques.

## Raté, puis corrigé

- Aucun incident technique majeur aujourd'hui, transition du projet validée collectivement.

## Décidé

- Le projet officiel de l'équipe 20 est désormais le Robot éducatif multipaysage.
- Utilisation de Fusion 360 pour l'ensemble de la conception mécanique des pièces personnalisées du robot.

## À faire demain

- Continuer la prise en main du logiciel fusion 360.
- Démarrer la modélisation des supports de capteurs (ultrason et infrarouges) et rédiger la première ébauche de la fiche projet et du plan en spirale (V0) pour le jalon.

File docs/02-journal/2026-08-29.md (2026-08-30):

# Journal du samedi 29 août 2026 (rédigé par : Komnakan YOMBOU)

## Fait aujourd'hui

- Atelier « Gestion de projet » : toutes les équipes réunies pour choisir leur projet de fin de formation à partir du recueil des 150 projets
- Analyse comparative de plusieurs pistes pour l'équipe 20, selon trois critères : faisabilité technique, pertinence éducative, richesse en compétences acquises
- Étude d'une variante combinant horloge parlante et afficheur d'informations d'établissement (heure, cours, pause, communiqué)
- Choix final arrêté par l'équipe 20 : **P126 — Indicateur de niveau sonore de classe**, avec une adaptation propre à l'équipe (bouton Mode Cours) pour éviter les faux déclenchements pendant un cours magistral ou la prise de parole d'un élève interrogé

## Appris

- La méthode de sélection d'un projet ne se limite pas à l'envie : elle croise faisabilité, pertinence pour l'établissement, et richesse d'apprentissage
- L'exigence ET-FAB-02 impose au moins trois procédés de fabrication distincts par projet : un critère qui a pesé dans la comparaison des pistes
- Aucune fabrication n'est autorisée avant la validation de la fiche projet par l'encadreur référent : le jalon J1 porte sur un livrable de cadrage, pas encore sur un objet physique

## Raté, puis corrigé

- L'équipe a d'abord envisagé de combiner deux projets : Étude d'une variante combinant indicateur de niveau sonore de classe, un diffiseur qui émet un bruit ou un son lorsque le niveau sonore dans la salle est élevé, un tableau qui affiche en temps réel la mesure du niveau sonore et des sorties Leds pour indiquer les avertissements et une signalisation au proviseur, surveillant ou directeur. Mais après réflexion, nous avons laissé tomber le diffuseur car trop bruyant et pertubant pour les salles de classes à périphérie, l'écran qui va distraire les élèves. Donc comme sorties, nous n'aurons que des Leds et une signalisation chez le surveillant ou le directeur si le niveau sonore ne diminue pas après plusieurs avertissements.
## Décidé

- Le projet retenu par l'équipe 20 est P126 — Indicateur de niveau sonore de classe.
- Une fonctionnalité supplémentaire est ajoutée au périmètre socle : un bouton Mode Cours, pour garantir que le dispositif régule le bruit du groupe et non la parole encadrée par l'enseignant.

## À faire

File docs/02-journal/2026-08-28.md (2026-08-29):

# Journal du vendredi 28 août 2026 (rédigé par : Komnakan YOMBOU)

## Fait aujourd'hui

- Atelier « Impression 3D » : édition d'un support de téléphone dans Bambu Studio, puis impression
  Interface Bambu Studio — support de téléphone
  Support de téléphone imprimé
- Atelier « Découpe laser » : gravure puis découpe de la carte de visite conçue le 27 août
  Carte de visite gravée et découpée
- Atelier « Électronique » : programmation du CyberPi avec le capteur de lumière pour allumer les LED uniquement la nuit (seuil : luminosité < 50)
  Programme mBlock — allumage conditionné à la luminosité
  CyberPi en condition de jour — LED éteintes
  CyberPi en condition de nuit — LED allumées
- Atelier « Gestion de projet » : présentation du design thinking et de la méthode en spirale, étapes de chacune des deux méthodes

## Appris

- Le design thinking est une démarche centrée sur l'utilisateur, généralement organisée en cinq étapes (empathie, définition du problème, idéation, prototypage, test), répétées de façon itérative jusqu'à ce que la solution réponde vraiment au besoin.
- La méthode en spirale, structure un projet en boucles successives comportant chacune quatre temps : fixer les objectifs et contraintes, analyser les risques, développer et vérifier la solution retenue, puis revoir les résultats avant de relancer un nouveau tour. Contrairement à un déroulé linéaire, l'accent est mis sur la gestion du risque à chaque tour.
- Pour notre projet de fin de formation à but éducatif, ces deux méthodes se complètent : le design thinking pour bien cerner le problème éducatif à résoudre et imaginer des pistes centrées sur l'utilisateur (élève, enseignant), la spirale pour cadrer les itérations de fabrication en tenant compte des risques (délais, matériel, faisabilité technique) jusqu'au jalon final.

## Raté, puis corrigé

## Décidé

## À faire demain

- Chaque groupe va choisir son projet.

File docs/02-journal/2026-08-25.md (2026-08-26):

# Journal du mardi 25 août 2026 (rédigé par : Komnakan YOMBOU)

## Fait aujourd'hui

- Reçu par mail l'invitation à rejoindre l'organisation GitHub de la formation, et rejoint le groupe
- Créé le dépôt de l'équipe dans l'organisation GitHub
- Créé le fichier `docs/02-journal/2026-08-25.md`
- Copié l'URL du dépôt distant depuis GitHub
- Dans VSCode : initialisé un dépôt local
- Configuré l'identité Git en ligne de commande : `git config --global user.email y********n@gmail.com` et `git config --global user.name S************`
- Réalisé le commit initial du dossier de travail
- Relié le dépôt local au dépôt distant avec origin
- Vérifié sur GitHub : le dossier et les fichiers sont bien présents en ligne
- Découverte du réseau FabLabs et de sa charte

## Appris

- Créer un dépôt GitHub, le relier à VS Studio Code
- Un dépôt local n'est pas encore relié à GitHub tant que `remote add` n'a pas été fait
- L'historique des FabLabs
- La différence entre FabLabs et MarkerSpaces
- Comment les FabLabs ont débuté et évoluer avec le temps
- La charte des FabLabs via [Charte Internationale des FabLabs](https://fablab.grandbesancon.fr/charte/)

## Raté, puis corrigé

- Le premier `commit` a échoué avec un message d'erreur → cause : les commandes `git config --global user.email` et `git config --global user.name` n'avaient pas encore été lancées, Git ne connaissait donc pas l'identité de l'auteur → correction : exécution des deux commandes de configuration, puis nouvelle tentative de commit → résultat : commit accepté, et après `push`, le dépôt GitHub était bien à jour

## Décidé

- Utiliser `git init` + `git remote add origin` plutôt que `git clone`, le dossier de travail ayant déjà été créé localement avant la copie du lien GitHub

## À faire demain

- Présentation du cahier de charge.

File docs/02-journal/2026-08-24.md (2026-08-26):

# Journal du lundi 24 août 2026 (rédigé par : Komnakan YOMBOU)

## Fait aujourd'hui

- Assisté à l'ouverture officielle de la formation par le Ministre
- Participé aux présentations croisées formés / formateurs, et aux échanges sur le projet à mener
- Installé Git et Visual Studio Code sur le poste de travail
- Créé un compte GitHub personnel
- Renommé le fichier modèle du journal : suppression de `2026-08-25.md`, création de `2026-08-24.md`

## Appris

- Répartition des rôles entre VSCode (écriture), Git (historique local) et GitHub (partage en ligne)
- La convention de nommage des entrées de journal est `AAAA-MM-JJ.md`, une par jour ouvré

## Raté, puis corrigé

- Le fichier modèle fourni portait la date du 25/08 (date de J0 sur le calendrier officiel) → or les activités réelles (ouverture, installation des outils) ont commencé le 24/08 → correction : suppression du fichier daté du 25 et création d'un fichier daté du 24, pour que le journal reflète la date réelle du travail, conformément au principe « documentation datée et honnête »

## Décidé

- Faire démarrer le journal quotidien dès le 24/08 (jour réel de début d'activité) plutôt qu'au 25/08 (J0 du calendrier), pour ne perdre aucune trace du travail effectué

## À faire demain

- Rejoindre l'organisation GitHub de la formation suite à l'invitation par mail
- Créer le dépôt de l'équipe à partir du modèle imposé

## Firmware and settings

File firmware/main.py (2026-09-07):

from machine import Pin, I2C
from ssd1306 import SSD1306_I2C
import dht, time
 
capteur = dht.DHT11(Pin(4))                      # DHT22 sur D3 (GPIO4)
i2c = I2C(0, scl=Pin(6), sda=Pin(5), freq=400000) # I2C sur D4/D5
oled = SSD1306_I2C(128, 64, i2c)
 
while True:
    try:
        capteur.measure()
        t, h = capteur.temperature(), capteur.humidity()
        oled.fill(0)
        oled.text('Station meteo', 0, 0)
        oled.text('Temp: {:.1f} C'.format(t), 0, 24)
        oled.text('Hum : {:.1f} %'.format(h), 0, 40)
        oled.show()
    except OSError as e:
        print('Erreur capteur:', e)
    time.sleep(2)

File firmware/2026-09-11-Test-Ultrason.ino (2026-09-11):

const int TRIG_PIN = 9;
const int ECHO_PIN = 10;

void setup() {
  Serial.begin(9600);

  pinMode(TRIG_PIN, OUTPUT);
  pinMode(ECHO_PIN, INPUT);

  digitalWrite(TRIG_PIN, LOW);
}

void loop() {
  // Envoyer une impulsion ultrasonique
  digitalWrite(TRIG_PIN, LOW);
  delayMicroseconds(2);

  digitalWrite(TRIG_PIN, HIGH);
  delayMicroseconds(10);

  digitalWrite(TRIG_PIN, LOW);

  // Mesurer le temps de retour
  long duree = pulseIn(ECHO_PIN, HIGH);

  // Calculer la distance en cm
  float distance = duree * 0.0343 / 2;

  Serial.print("Distance : ");
  Serial.print(distance);
  Serial.println(" cm");

  delay(500);
}

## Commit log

2026-08-27 docs(journal): Entrée du 26 Août 2026 avec une photo de la découpe Laser
2026-09-03 docs(journal): Entrée du 02 septembre
    [Foldable_Phone_Stand_Bambu.3mf, Foldable_Phone_Stand_Bambu.gcodeYK.gcode.3mf, Foldable_Phone_Stand_Bambu.stl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]
2026-09-08 docs(journal): Entrée du 07 Septembre
    [2026-09-07-PCB01.kicad_pcb, 2026-09-07-PCB01.kicad_sch]
2026-09-16 docs(journal): Entrée des 15 et 16 septembre
    [2026-09-16-ROBOT_EDU-B_Cu.dxf, 2026-09-16-ROBOT_EDU-Edge_Cuts.dxf, 2026-09-16-ROBOT_EDU.kicad_pcb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]
2026-09-16 docs(journal): Entrée complète des 15 et 16 Septembre
2026-09-18 docs(journal): Entrée du 18 Septembre
    [composants.csv]
